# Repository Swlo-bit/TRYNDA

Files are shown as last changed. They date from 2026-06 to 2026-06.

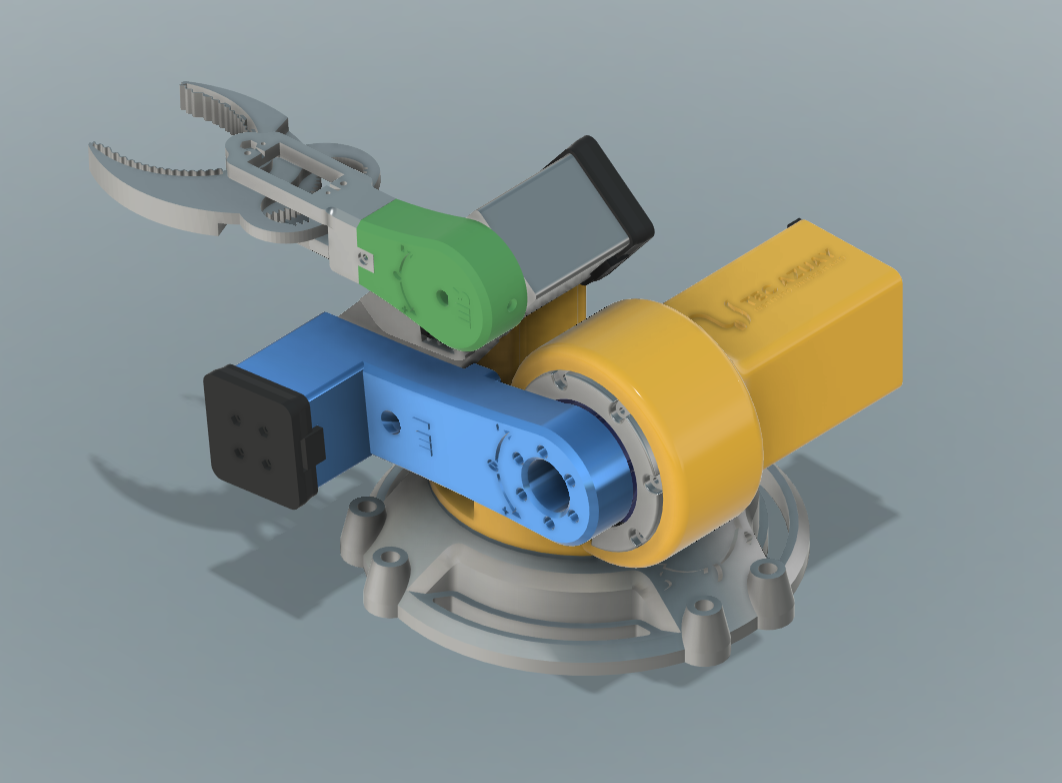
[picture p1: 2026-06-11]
TRYNDA 3D/Ensamble 1 TRYNDA.png

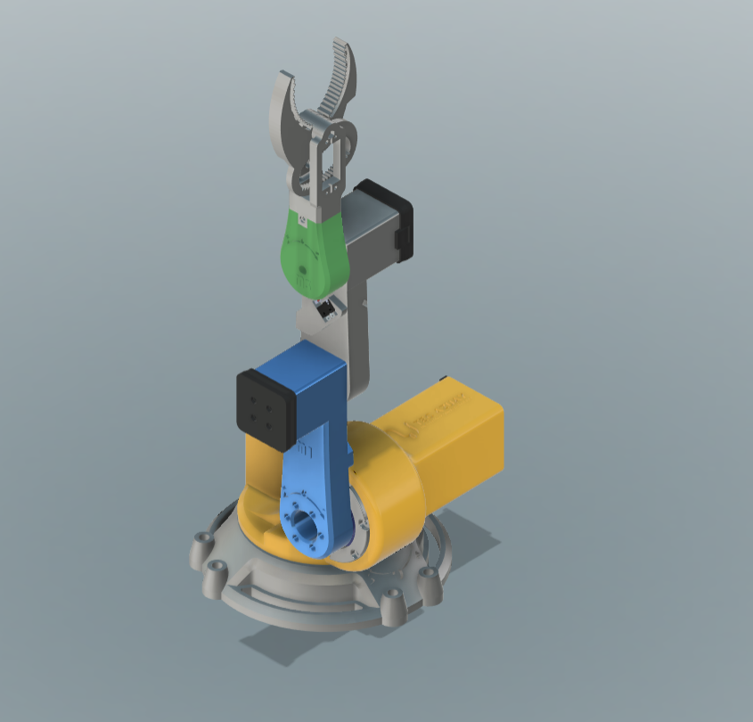
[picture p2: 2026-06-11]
TRYNDA 3D/Ensamble 2 TRYNDA.png

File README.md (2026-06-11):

# Robot Manipulador Mecatrónico de 4 GDL con Programación de Trayectorias

Ensamble 1 TRYNDA

## Descripción

Este proyecto corresponde al desarrollo de un robot manipulador de 4 grados de libertad más un gripper, realizado como proyecto integrador de la carrera de Mecatrónica.

El sistema reúne conocimientos adquiridos durante la formación académica en áreas como electrónica, automatización, control, programación, comunicaciones industriales, diseño mecánico, manufactura e impresión 3D.

El robot permite el control manual de cada articulación, la programación de posiciones mediante enseñanza por puntos, el posicionamiento por ángulos y la reproducción automática de trayectorias previamente almacenadas.

Aunque el sistema es completamente funcional, constituye una plataforma abierta que puede ser mejorada en futuras versiones mediante algoritmos avanzados de cinemática, planificación de trayectorias, visión artificial y sistemas de control más sofisticados.

## Características Principales

* Control de 4 grados de libertad más gripper.
* Homing automático mediante finales de carrera.
* Retroalimentación absoluta mediante encoders AS5600.
* Programación por puntos (Teach & Repeat).
* Programación por ángulos.
* Control manual mediante joystick.
* Comunicación inalámbrica ESP-NOW.
* Comunicación I²C entre controladores.
* Paro de emergencia local y remoto.
* Protección del gripper mediante monitoreo de corriente.
* Estructura fabricada principalmente mediante impresión 3D.

## Arquitectura de Comunicación y Sensado

Uno de los principales desafíos del proyecto fue la utilización de cuatro encoders magnéticos AS5600 para obtener la posición absoluta de cada articulación.

El AS5600 utiliza comunicación I²C y posee una dirección fija de fábrica (0x36), por lo que múltiples sensores no pueden coexistir en el mismo bus I²C sin generar conflictos de direccionamiento.

Para solucionar esta limitación se implementó una arquitectura distribuida:

* Cada articulación cuenta con un controlador dedicado.
* Cada Arduino Nano posee dos buses I²C independientes:

  * I²C hardware nativo para la comunicación con el sistema principal.
  * I²C por software (SoftwareWire) dedicado exclusivamente a su encoder AS5600.

De esta manera cada controlador puede comunicarse con su propio encoder utilizando una línea I²C aislada, evitando conflictos por direcciones duplicadas.

### Distribución de Comunicaciones

**ESP32 Maestro**

* Interfaz de usuario.
* Comunicación inalámbrica mediante ESP-NOW.

**ESP32 Esclavo**

* Coordinador general del robot.
* Comunicación ESP-NOW con el maestro.
* Comunicación I²C con los Arduino Nano.

**Arduino Nano Hombro**

* I²C hardware: comunicación con ESP32.
* I²C software: encoder AS5600.

**Arduino Nano Codo**

* I²C hardware: comunicación con ESP32.
* I²C software: encoder AS5600.

**Arduino Nano Muñeca**

* I²C hardware: comunicación con ESP32.
* I²C software: encoder AS5600.

Gracias a esta arquitectura fue posible utilizar múltiples encoders AS5600 simultáneamente sin necesidad de multiplexores I²C adicionales.
Esta solución permitió evitar el uso de multiplexores I²C externos, simplificando el hardware y distribuyendo la carga de procesamiento entre varios microcontroladores.

## Arquitectura del Sistema

El sistema está dividido en varios controladores distribuidos:

### ESP32 Maestro

Responsable de:

* Interfaz de usuario.
* Pantalla OLED.
* Teclado matricial.
* Joystick.
* Selección de modos de operación.
* Envío de comandos mediante ESP-NOW.

### ESP32 Esclavo M0

Responsable de:

* Coordinación general del robot.
* Control del eje Base (M1).
* Control del gripper.
* Gestión de trayectorias.
* Supervisión de seguridad.
* Comunicación con los Arduino Nano.

### Arduino Nano M1 (Hombro)

Responsable del control cerrado del eje hombro utilizando:

* Motor paso a paso.
* Encoder AS5600.
* Final de carrera para homing.

### Arduino Nano M2 (Codo)

Responsable del control cerrado del eje codo utilizando:

* Motor paso a paso.
* Encoder AS5600.
* Final de carrera para homing.

### Arduino Nano M3 (Muñeca)

Responsable del control cerrado del eje muñeca utilizando:

* Motor paso a paso.
* Encoder AS5600.
* Final de carrera para homing.

## Modos de Operación

El robot incorpora tres modos principales de programación y control, permitiendo tanto la manipulación manual como la ejecución automática de trayectorias.

### 1. Programación por Ángulos Incrementales

En este modo el operador selecciona una articulación específica y posteriormente introduce un valor angular mediante el teclado matricial.

El valor ingresado no corresponde a una posición absoluta, sino a un incremento respecto a la posición actual de la articulación.

Por ejemplo:

* Posición actual: 45°
* Valor ingresado: +20°
* Nueva posición objetivo: 65°

O bien:

* Posición actual: 45°
* Valor ingresado: -10°
* Nueva posición objetivo: 35°

Cada controlador calcula internamente la nueva posición objetivo sumando o restando el incremento al ángulo absoluto medido por su encoder AS5600.

### 2. Control Manual por Joystick

Este modo permite mover individualmente cualquiera de las articulaciones utilizando el joystick integrado en el control maestro.

El operador selecciona el eje deseado y puede realizar movimientos manuales en ambos sentidos para posicionar el robot de forma rápida e intuitiva.

Este modo es utilizado principalmente para:

* Posicionar manualmente el manipulador.
* Realizar pruebas de funcionamiento.
* Enseñar trayectorias.
* Ajustar posiciones antes de almacenarlas.

### 3. Programación por Puntos

Este modo permite crear trayectorias mediante enseñanza directa.

El usuario puede:

* Liberar una articulación específica.
* Liberar todas las articulaciones simultáneamente.
* Posicionar el robot manualmente.
* Posicionar el robot mediante joystick.
* Fijar nuevamente las articulaciones.
* Almacenar la posición actual como un punto de trayectoria.

Cada vez que se guarda un punto, el sistema registra simultáneamente:

* Posición de la base.
* Posición del hombro.
* Posición del codo.
* Posición de la muñeca.
* Posición del gripper.

Es decir, cada punto representa el estado completo del robot en un instante determinado.

Los puntos almacenados pueden reproducirse posteriormente de manera automática, permitiendo ejecutar secuencias repetitivas sin necesidad de reprogramación.

Actualmente el sistema permite almacenar hasta 20 puntos por rutina, valor que puede ampliarse en futuras versiones.

## Sistema de Seguridad

El robot incorpora múltiples mecanismos de seguridad:

* Paro de emergencia físico.
* Paro de emergencia remoto.
* Límites mecánicos por software.
* Homing obligatorio antes de operación.
* Supervisión de corriente en el gripper mediante INA219.
* Detección de fallos de comunicación con encoders AS5600.

## Hardware Utilizado

### Controladores

* 2 ESP32
* 3 Arduino Nano

### Sensores

* 4 Encoders magnéticos AS5600
* 1 Sensor de corriente INA219
* Finales de carrera mecánicos

### Actuadores

* 1  NEMA 23 (M1)
* 1  NEMA 17 (M0)
* 2  NEMA 17 5:1 (M2 & M3)
* 1  MG996R (Gripper o M5)

### Electrónica de Potencia

* 3 Driver TB6600
* Driver DM556
* Fuente 12V 10A
* 2 Convertidores LM2596

### Mecánica

* Piezas impresas en 3D
* Rodamientos
* Insertos roscados
* Pernos y tuercas
* Acoples mecánicos

## Fabricación

La estructura mecánica fue diseñada principalmente para fabricación mediante impresión 3D.

Debido a las altas cargas transmitidas por una de las articulaciones, fue necesario fabricar una pieza mecánica metálica para la unión del motor correspondiente, ya que la versión impresa no soportaba los esfuerzos generados durante la operación.

## Posibles Mejoras Futuras
* Implementación de cinemática inversa.
* Planificación automática de trayectorias.
* Interpolación lineal y circular.
* Integración con ROS.
* Sistema de visión artificial.
* Detección y seguimiento de objetos.
* Interfaz gráfica para programación.
* Monitoreo remoto mediante WiFi.
* Control avanzado de movimiento.

## Autores

* Sebastian A. Saico
* Saul Andrés Sánchez Barbecho
  * Email: saulsanchezbarbecho@gmail.com
* Jonnathan A. Valdez
* Edwin J. Suqui

Tecnología Superior en Mecatrónica
TECAZUAY – Ecuador

TRYNDA real

TRYNDA real 2

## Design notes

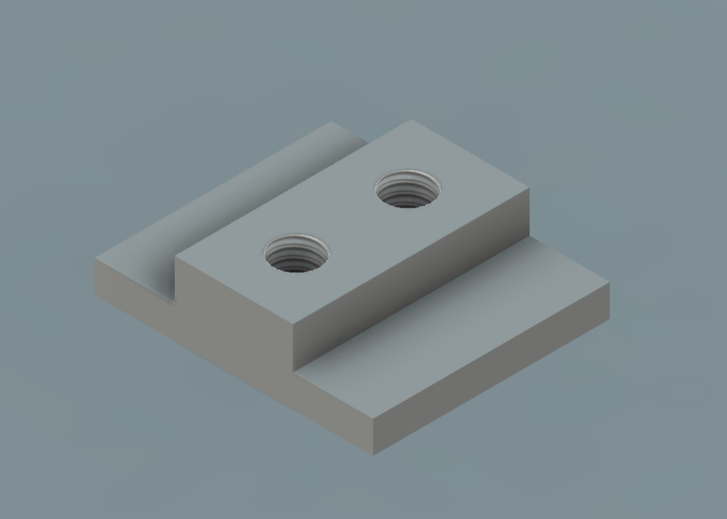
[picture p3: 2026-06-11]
Piezas Mecanicas/Soporte Nema M2.png

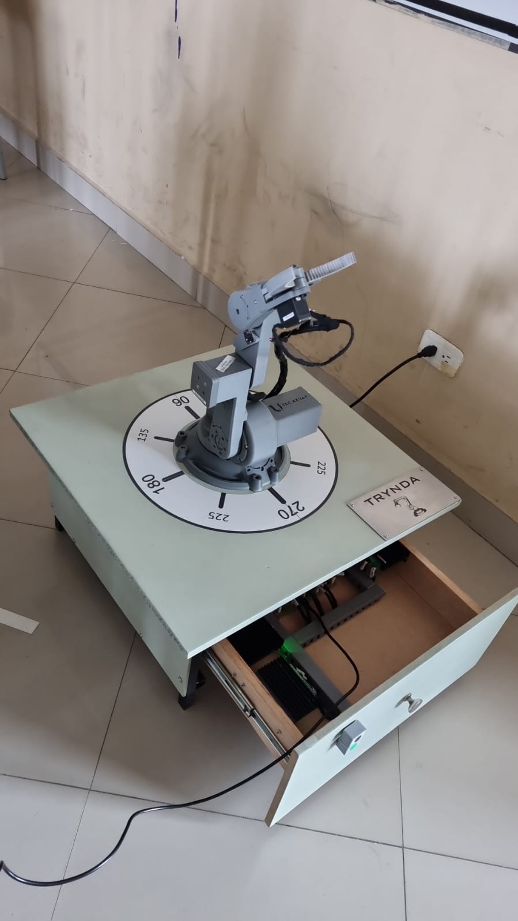
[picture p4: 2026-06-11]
TRYNDA 3D/TRYNDA real 2.jpeg

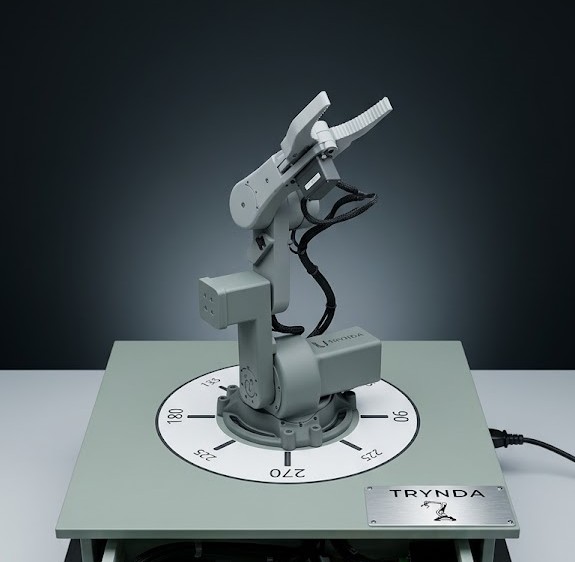
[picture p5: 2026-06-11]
TRYNDA 3D/TRYNDA real.jpeg

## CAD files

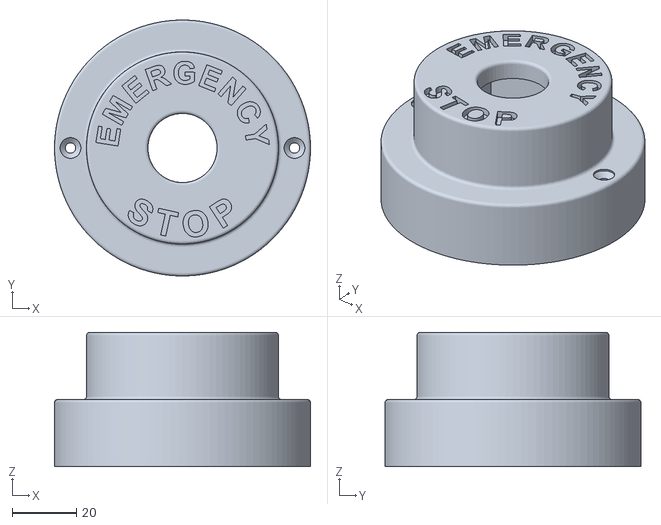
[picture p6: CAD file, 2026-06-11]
TRYNDA 3D/Emergency Stop.stl
80.0 x 80.0 x 42.0

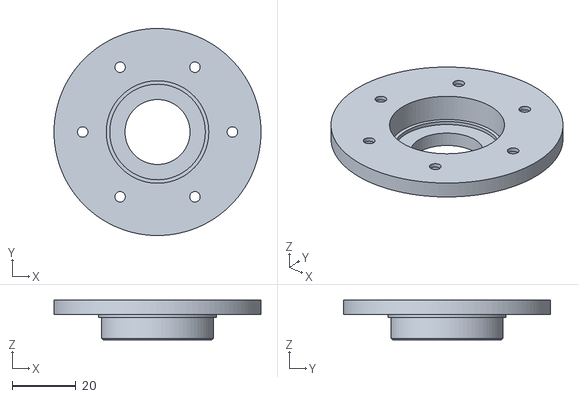
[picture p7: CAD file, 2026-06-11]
TRYNDA 3D/reductor/Soporte entrada.stl
65.0 x 65.0 x 12.5

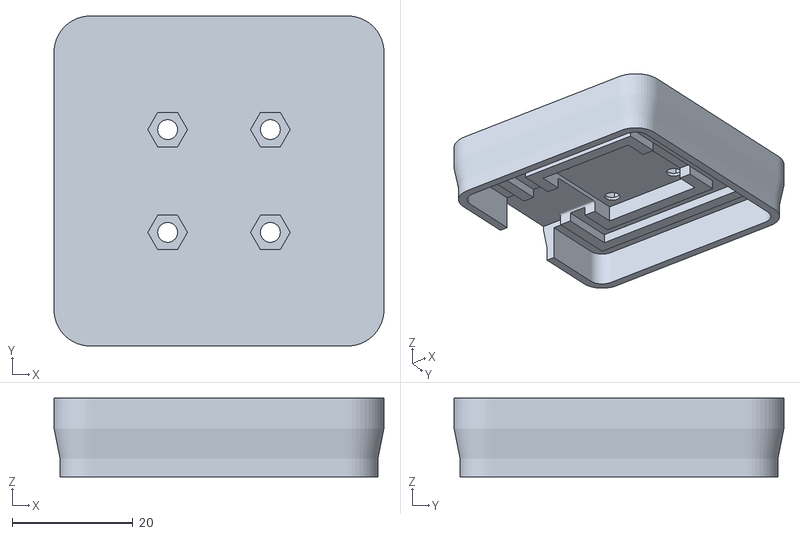
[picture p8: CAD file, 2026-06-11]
TRYNDA 3D/Bracket M2 TRYNDA.stl
54.6 x 54.6 x 13.0

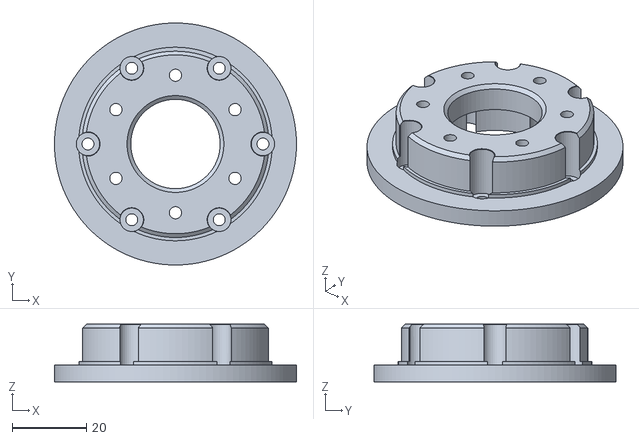
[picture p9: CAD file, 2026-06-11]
TRYNDA 3D/reductor/Salida reducida TRYNDA.stl
65.0 x 65.0 x 15.5

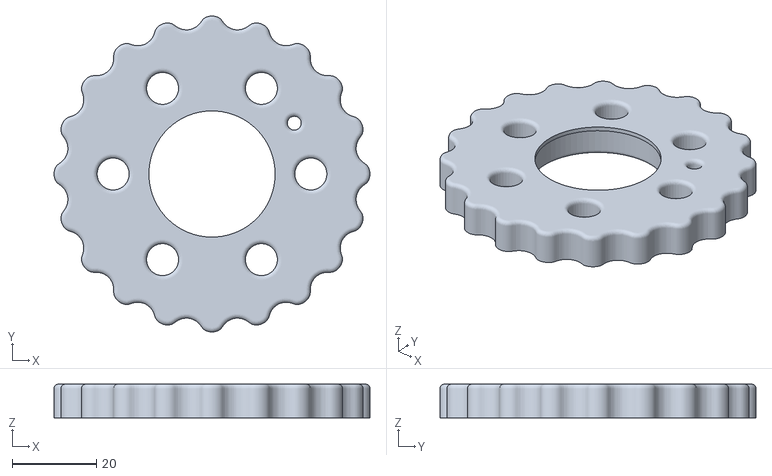
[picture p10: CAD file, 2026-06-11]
TRYNDA 3D/reductor/cycloid1.stl
75.1 x 75.1 x 8.00

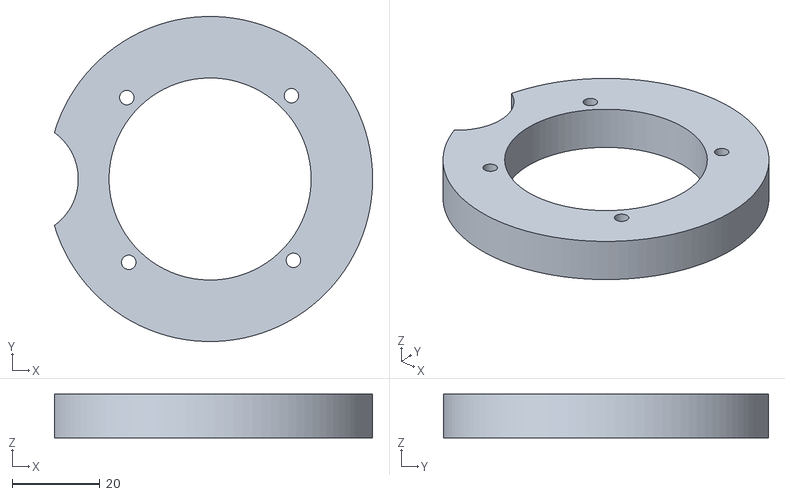
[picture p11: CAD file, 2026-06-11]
TRYNDA 3D/Tapa acople Base TRYNDA.stl
72.5 x 74.0 x 10.0

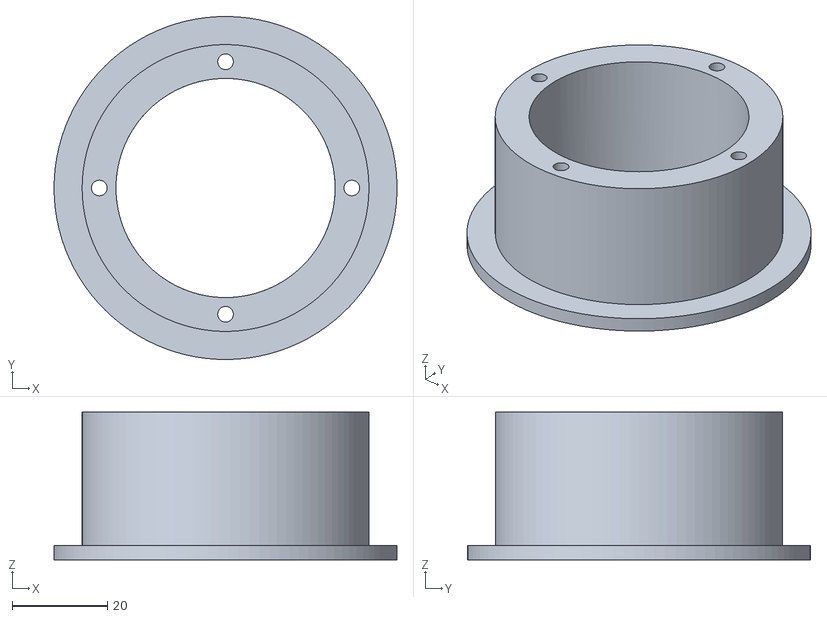
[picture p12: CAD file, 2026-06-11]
TRYNDA 3D/acople base TRYNDA.stl
72.0 x 72.0 x 31.0

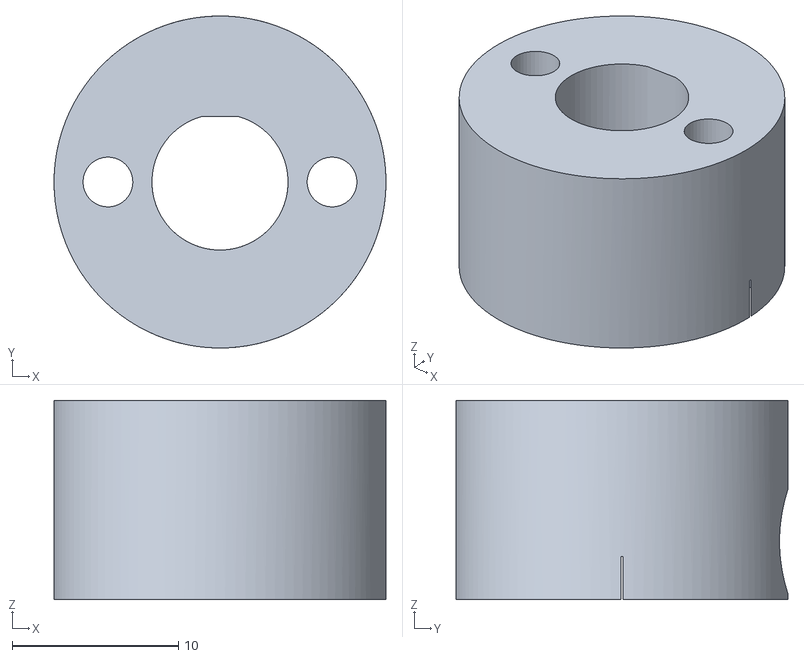
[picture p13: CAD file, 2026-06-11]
TRYNDA 3D/reductor/CAM input_.stl
20.0 x 20.0 x 12.0

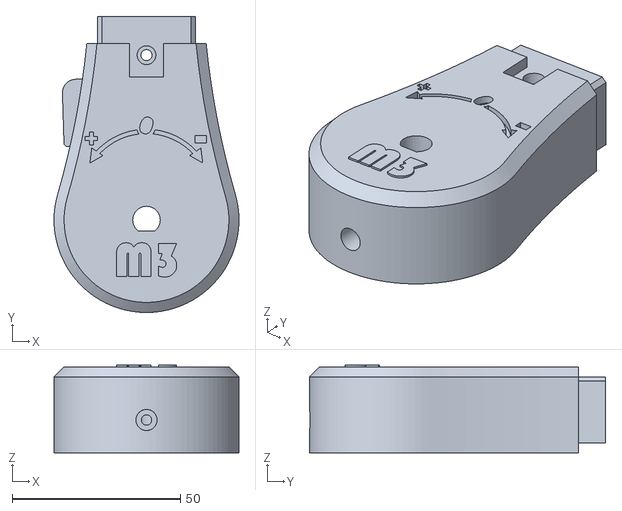
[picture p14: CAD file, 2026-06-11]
TRYNDA 3D/Articulacion M3 TRYNDA.stl
55.0 x 88.0 x 26.1

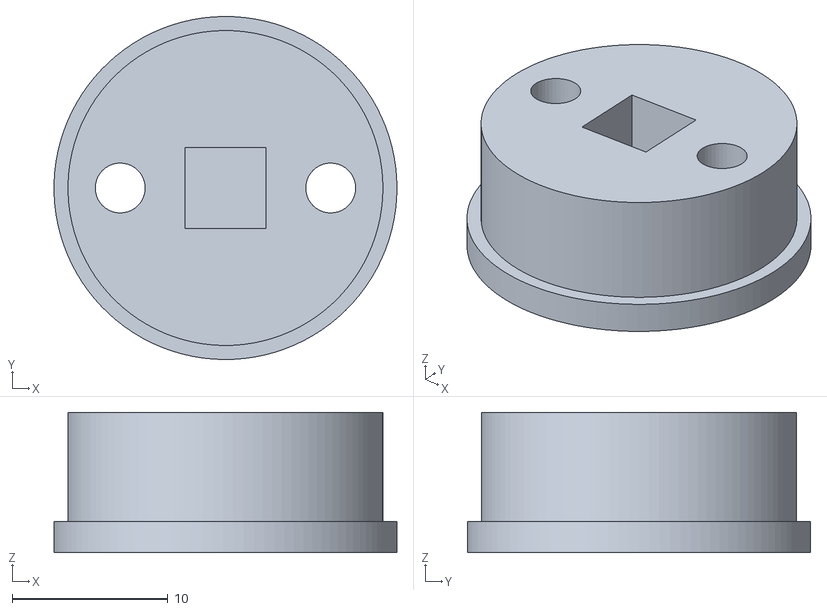
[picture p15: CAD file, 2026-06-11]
TRYNDA 3D/reductor/cam4.stl
22.0 x 22.0 x 9.00

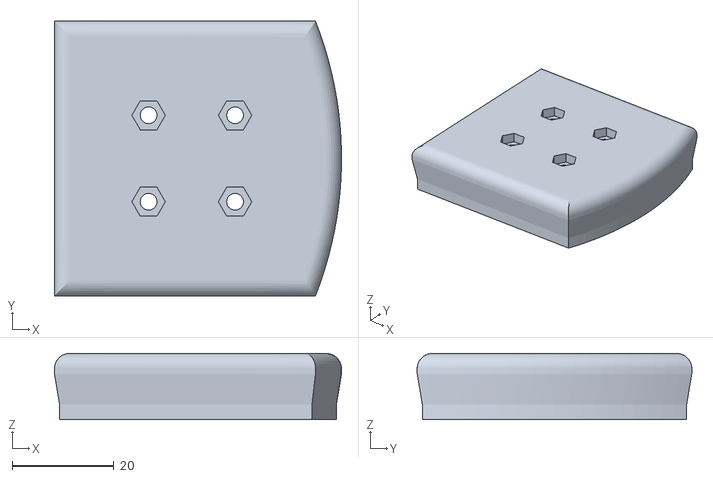
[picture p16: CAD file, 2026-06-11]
TRYNDA 3D/Bracket M0 TRYNDA.stl
56.4 x 54.0 x 13.0

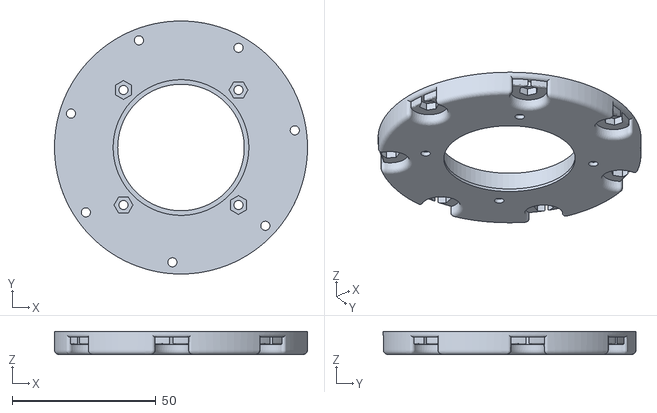
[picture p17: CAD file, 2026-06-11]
TRYNDA 3D/reductor/Cuerpo Bajo.stl
88.0 x 88.0 x 8.00

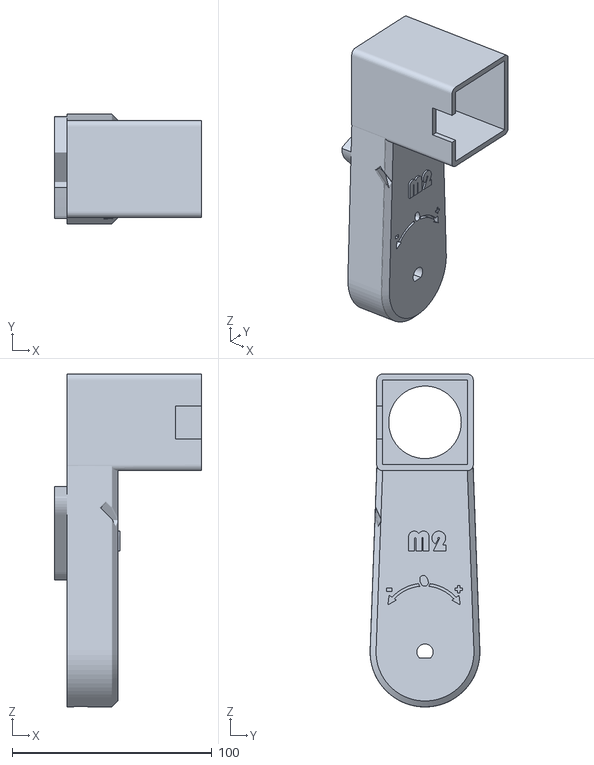
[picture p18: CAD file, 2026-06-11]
TRYNDA 3D/Articulacion M2 TRYNDA.stl
73.8 x 55.0 x 166.7

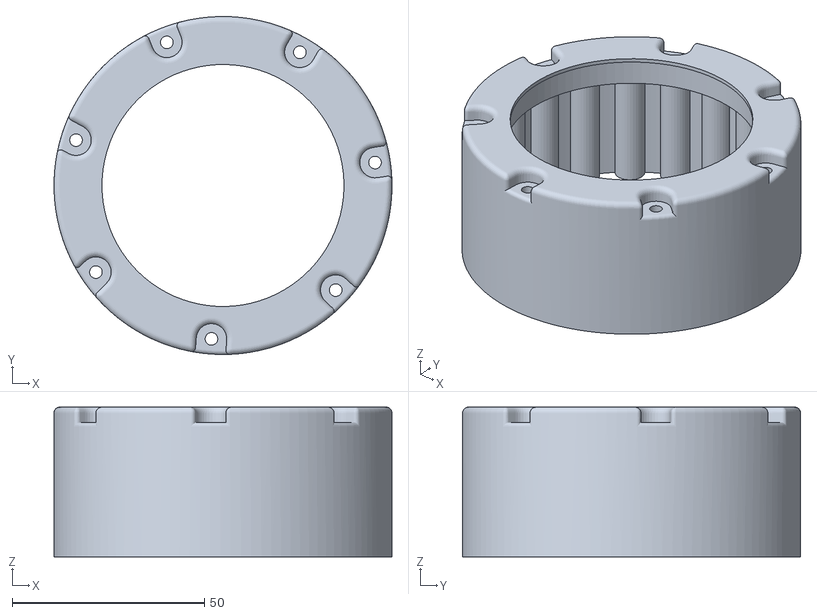
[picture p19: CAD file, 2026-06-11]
TRYNDA 3D/reductor/Soporte Exterior TRYNDA.stl
88.0 x 88.0 x 39.0

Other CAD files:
TRYNDA 3D/reductor/CAM 1 - 2.stl
TRYNDA 3D/Base TRYNDA.stl
TRYNDA 3D/reductor/cycloid2.stl
TRYNDA 3D/Articulacion M1 TRYNDA.stl
TRYNDA 3D/Bracket M1 TRYNDA.stl
TRYNDA 3D/reductor/Acople nema23.stl
TRYNDA 3D/reductor/CAM 3.stl

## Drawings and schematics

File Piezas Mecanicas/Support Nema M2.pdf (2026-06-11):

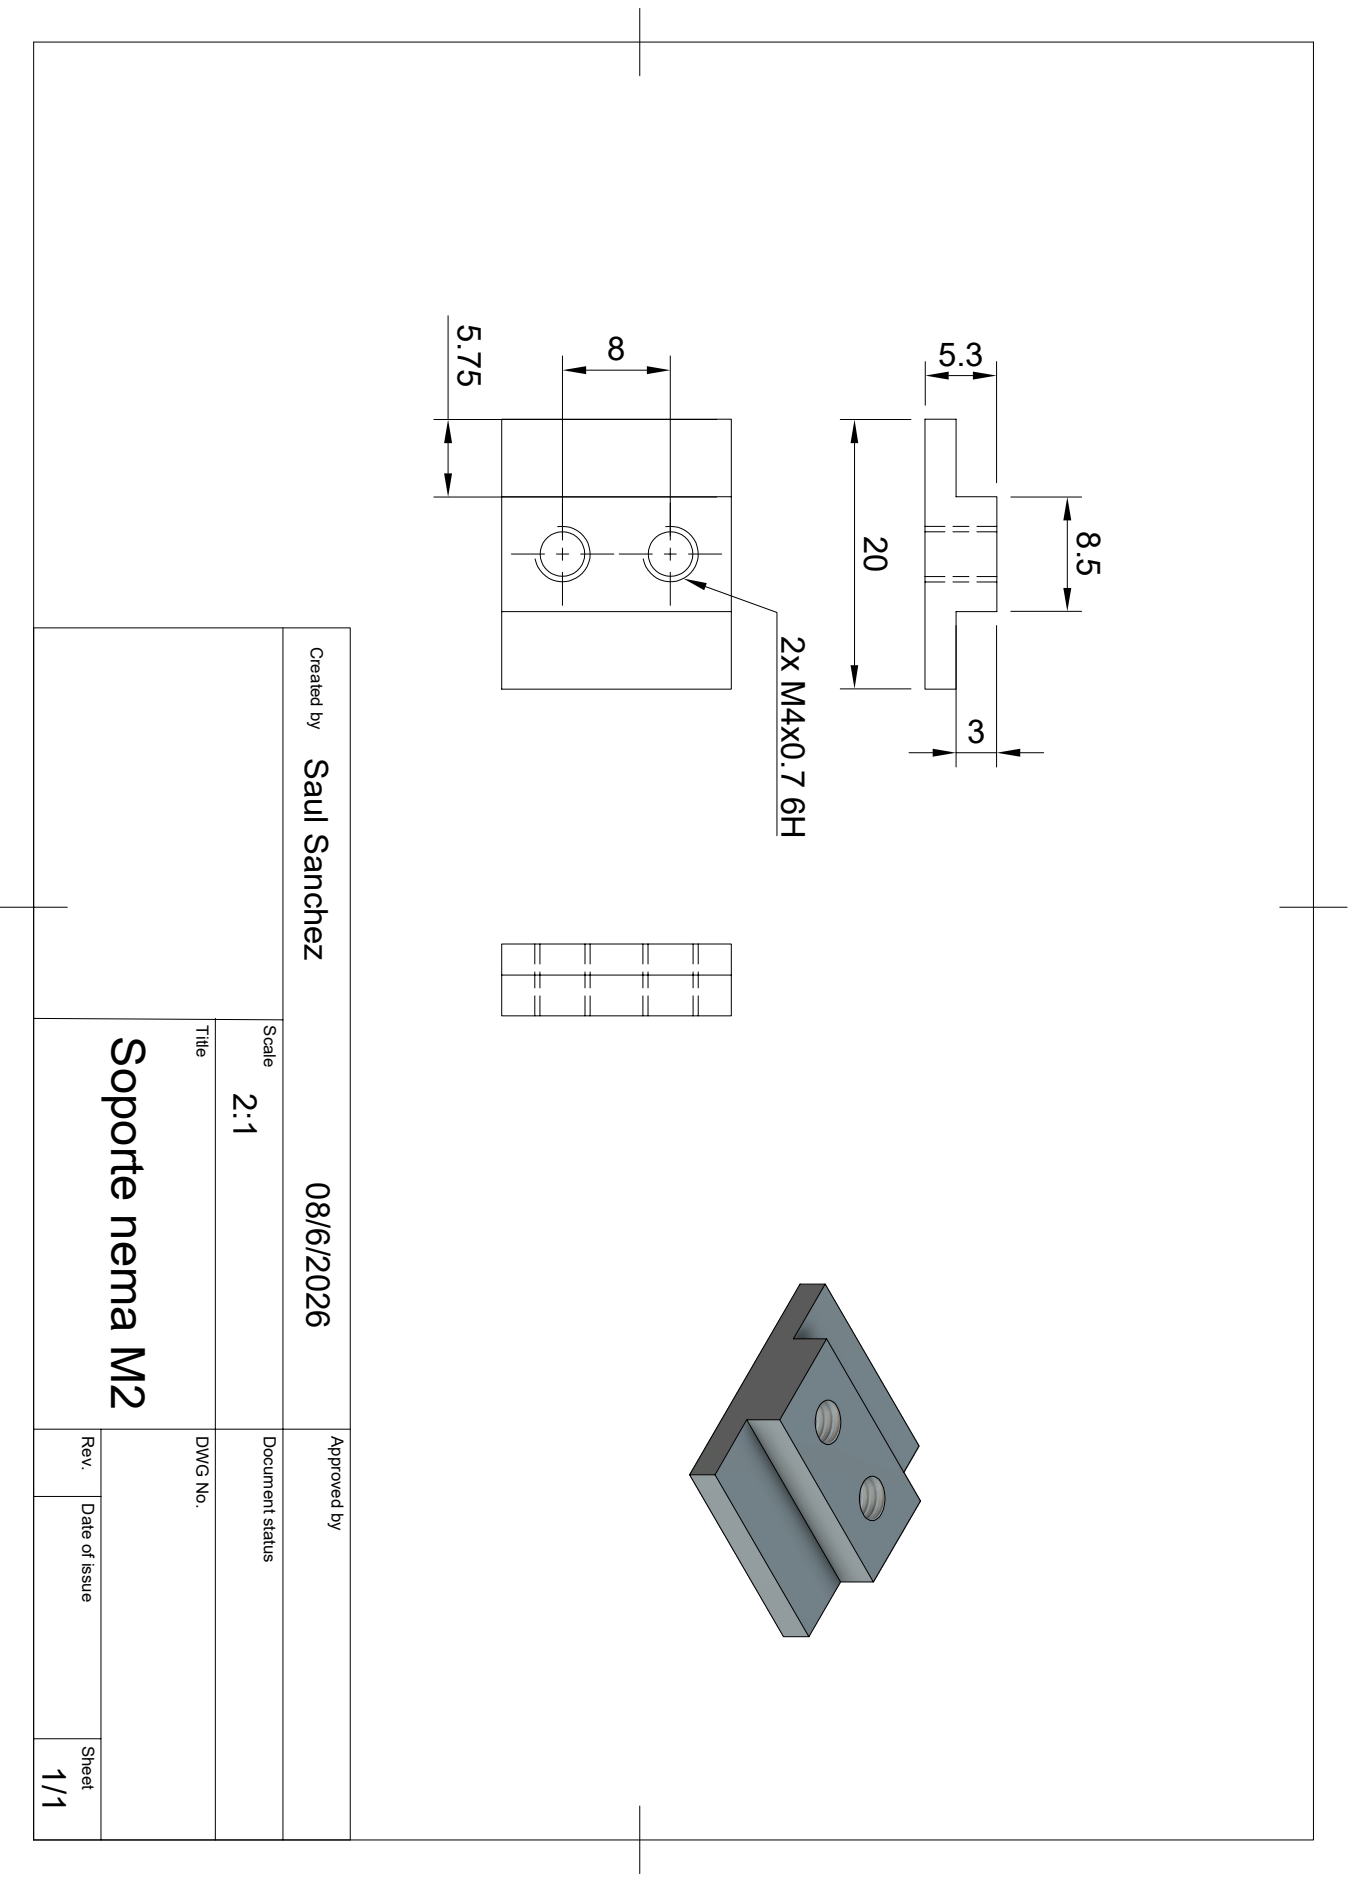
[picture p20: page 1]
8 Created by Approved by Title DWG No.; Scale Document status Rev. Date of issue Sheet; Soporte nema M2; Saul Sanchez

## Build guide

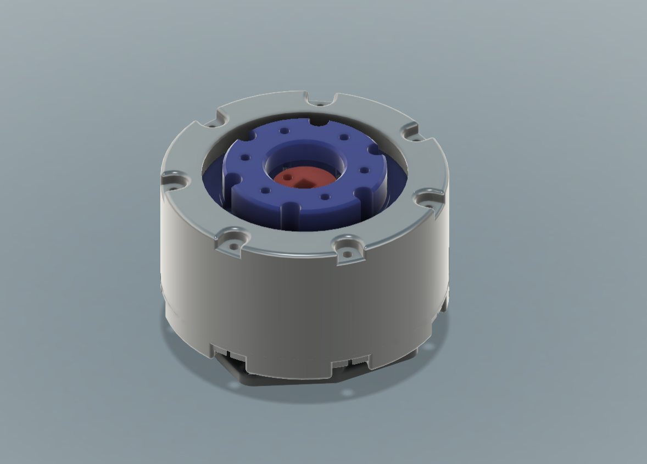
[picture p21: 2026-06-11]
TRYNDA 3D/reductor/Ensamble Reducotr Nema 23.png

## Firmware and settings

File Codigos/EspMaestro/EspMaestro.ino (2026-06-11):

#include <WiFi.h>
#include <esp_now.h>
#include <U8g2lib.h>
#include <Wire.h>
#include <Keypad.h>

U8G2_SH1106_128X64_NONAME_F_HW_I2C oled(U8G2_R0, U8X8_PIN_NONE);

#define PIN_PARO 23 
bool sistemaBloqueado = false;
bool paroRemoto = false;

#define VRX 34 
#define VRY 35 
#define SW_PIN 5 
int centroVRX = 0, centroVRY = 0; 

#define LED_JOYSTICK 15 
#define LED_ANGULOS   2 
#define LED_PUNTOS    4 

const byte FILAS = 4;
const byte COLS  = 4;
char teclas[FILAS][COLS] = {
  {'1','2','3','A'},
  {'4','5','6','B'},
  {'7','8','9','C'},
  {'*','0','#','D'}
};

byte pinesFilas[FILAS]    = {27, 14, 12, 13};
byte pinesColumnas[COLS]  = {32, 33, 25, 26};
Keypad keypad = Keypad(makeKeymap(teclas), pinesFilas, pinesColumnas, FILAS, COLS);

uint8_t slaveMAC[] = {0x88, 0x57, 0x21, 0x8B, 0x3D, 0x58};
typedef struct { char msg[24]; } Packet;
Packet packet;

bool enControlJoystick = false;     
bool enSeleccionMotor = false;    
bool enDigitacionAngulo = false; 
int menuActual = 0;
int cursorMenu = 0;
int motorSeleccionado = 1;

const int NUM_MOTORES = 5;
String nombresMotores[NUM_MOTORES] = {"Base", "Hombro", "Codo", "Muneca", "Garra"};
int cursorMotor = 0;
String estadoMotor = "STOP";
String ultimoEstado = "";
int puntosGuardadosCount = 0;
String inputAngulo = ""; 

unsigned long lastButtonPress = 0;
const int doubleClickTime = 500;
bool lastButtonState = HIGH;

void onDataRecv(const esp_now_recv_info_t *info, const uint8_t *data, int len) {
  memcpy(&packet, data, sizeof(packet));
  String msg = String(packet.msg); msg.trim();
  if (msg == "EMERGENCIA_ON") paroRemoto = true;
  else if (msg == "EMERGENCIA_OFF") paroRemoto = false;
}

// 🔥 NUEVA FUNCIÓN: Saludo de inicio
void saludoInicial() {
  oled.setFont(u8g2_font_ncenB14_tr);
  
  oled.clearBuffer();
  int w1 = oled.getStrWidth("Hello!");
  oled.drawStr((128 - w1) / 2, 40, "Hello!");
  oled.sendBuffer();
  delay(1200);

  oled.clearBuffer();
  int w2 = oled.getStrWidth("Hola!");
  oled.drawStr((128 - w2) / 2, 40, "Hola!");
  oled.sendBuffer();
  delay(1200);

  oled.clearBuffer();
  int w3 = oled.getStrWidth("Ni hao!");
  oled.drawStr((128 - w3) / 2, 40, "Ni hao!");
  oled.sendBuffer();
  delay(1200);
}

void pantallaBloqueo() {
  static bool parpadeo = false;
  oled.clearBuffer();
  if (parpadeo) oled.drawFrame(0, 0, 128, 64);
  oled.drawFrame(2, 2, 124, 60);
  oled.setFont(u8g2_font_ncenB10_tr);
  oled.drawStr(30, 28, "BLOQUEO");
  oled.setFont(u8g2_font_6x10_tr);
  if (paroRemoto) oled.drawStr(20, 48, "PARO ESCLAVO");
  else oled.drawStr(20, 48, "PARO MAESTRO");
  oled.sendBuffer();
  parpadeo = !parpadeo;
}

void pantallaLiberacion() {
  oled.clearBuffer(); oled.drawBox(4, 12, 120, 40); oled.setDrawColor(0);
  oled.setFont(u8g2_font_ncenB08_tr); oled.drawStr(20, 30, "SISTEMA LIBRE");
  oled.setFont(u8g2_font_5x8_tf); oled.drawStr(15, 45, "LISTO PARA OPERAR");
  oled.setDrawColor(1); oled.sendBuffer(); delay(1500);
}

void apagarLeds() {
  digitalWrite(LED_JOYSTICK, LOW); digitalWrite(LED_ANGULOS, LOW); digitalWrite(LED_PUNTOS, LOW);
}

void enviarESPNow(String txt) {
  txt.toCharArray(packet.msg, sizeof(packet.msg));
  esp_now_send(slaveMAC, (uint8_t*)&packet, sizeof(packet));
}

void drawIcon(uint8_t type, int x, int y) {
  switch (type) {
    case 0: oled.drawCircle(x+4,y,2); oled.drawLine(x+4,y-4,x+4,y+4); oled.drawLine(x,y,x+8,y); break;
    case 1: oled.drawCircle(x+4,y,1); oled.drawArc(x+4,y,6,0,90); break;
    case 2: oled.drawCircle(x+4,y+2,3); oled.drawLine(x+4,y-4,x+4,y+2); break;
  }
}

void drawItem(uint8_t pos, uint8_t index, const char* text) {
  int y = 4 + pos * 20;
  if (cursorMenu == index) oled.drawFrame(0, y, 128, 18);
  drawIcon(index, 6, y + 9); oled.drawStr(24, y + 13, text);
}

void mostrarMenuPrincipal() {
  apagarLeds(); oled.clearBuffer(); oled.setFont(u8g2_font_5x8_tf);
  drawItem(0, 0, "Prog. Puntos"); drawItem(1, 1, "Prog. Angulos"); drawItem(2, 2, "Prog. Joystick");
  oled.sendBuffer();
}

void mostrarMenuMotores() {
  oled.clearBuffer(); oled.setFont(u8g2_font_5x8_tf);
  if(menuActual == 1) oled.drawStr(0, 8, "MODO PUNTOS");
  else if(menuActual == 2) oled.drawStr(0, 8, "MODO ANGULOS");
  else oled.drawStr(0, 8, "MODO JOYSTICK");
  
  for (int i = 0; i < NUM_MOTORES; i++) {
    int y = 20 + i * 10;
    if (i == cursorMotor) oled.drawStr(0, y, ">"); 
    oled.drawStr(10, y, ("M" + String(i+1) + ": " + nombresMotores[i]).c_str());
  }
  oled.sendBuffer();
}

void mostrarIngresoAngulo() {
  oled.clearBuffer(); oled.setFont(u8g2_font_6x10_tf);
  oled.drawStr(0, 12, ("ANG: " + nombresMotores[motorSeleccionado-1]).c_str());
  oled.setFont(u8g2_font_ncenB14_tr); oled.drawStr(10, 40, inputAngulo.c_str());
  oled.setFont(u8g2_font_5x8_tf); oled.drawStr(0, 63, "*: +/-  D:Back  #:Go");
  oled.sendBuffer();
}

void mostrarEstadoMotor(String motor, String estado) {
  oled.clearBuffer(); oled.setFont(u8g2_font_5x8_tf);
  oled.drawStr(0, 10, ("MOTOR: " + motor).c_str());
  
  if (menuActual == 3) { 
    int cx = 64; int cy = 40;
    if (estado == "NEGATIVE") oled.drawBox(cx-12, cy-4, 24, 6);
    else if (estado == "POSITIVE") { oled.drawBox(cx-12, cy-4, 24, 6); oled.drawBox(cx-3, cy-13, 6, 24); } 
    else oled.drawDisc(cx, cy, 6); 
    oled.drawStr(0, 62, estado.c_str());
  } 
  else if (menuActual == 1) { 
    // 🔥 AUTO-CENTRADO para que encaje perfecto "POSITIVE" o "FREE"
    oled.setFont(u8g2_font_ncenB10_tr);
    int textWidth = oled.getStrWidth(estado.c_str());
    oled.drawStr((128 - textWidth) / 2, 35, estado.c_str()); 
    
    oled.setFont(u8g2_font_5x8_tf);
    oled.drawStr(0, 53, "*:Lib #:Fij   Pts:");
    oled.setCursor(95, 53); oled.print(puntosGuardadosCount);
    oled.drawStr(0, 63, "1:LibTodos 2:FijTodos");
  }
  
  oled.sendBuffer();
}

void mostrarTexto(String l1, String l2 = "") {
  oled.clearBuffer(); oled.setFont(u8g2_font_5x8_tf);
  oled.drawStr(0, 22, l1.c_str()); oled.drawStr(0, 40, l2.c_str());
  oled.sendBuffer();
}

void controlJoystickLoop() {
  int x = analogRead(VRX), y = analogRead(VRY);
  const int DZ = 700; 
  int diffX = abs(x - centroVRX), diffY = abs(y - centroVRY);
  if (diffX > diffY && diffX > DZ) estadoMotor = (x < centroVRX) ? "NEGATIVE" : "POSITIVE"; 
  else if (diffY > diffX && diffY > DZ) estadoMotor = (y < centroVRY) ? "NEGATIVE" : "POSITIVE"; 
  else estadoMotor = "STOP";

  if (estadoMotor != ultimoEstado) {
    ultimoEstado = estadoMotor;
    enviarESPNow("M" + String(motorSeleccionado) + "_" + estadoMotor);
    mostrarEstadoMotor(nombresMotores[motorSeleccionado-1], estadoMotor);
  }
}

void setup() {
  pinMode(PIN_PARO, INPUT_PULLUP);
  pinMode(LED_JOYSTICK, OUTPUT); pinMode(LED_ANGULOS, OUTPUT); pinMode(LED_PUNTOS, OUTPUT);
  pinMode(SW_PIN, INPUT_PULLUP);
  apagarLeds();
  
  Wire.begin(21, 22); 
  oled.begin();

  saludoInicial();

  WiFi.mode(WIFI_STA); esp_now_init(); esp_now_register_recv_cb(onDataRecv);
  esp_now_peer_info_t peerInfo = {}; memcpy(peerInfo.peer_addr, slaveMAC, 6); esp_now_add_peer(&peerInfo);
  long sumX = 0, sumY = 0;
  for (int i = 0; i < 20; i++) { sumX += analogRead(VRX); sumY += analogRead(VRY); delay(10); }
  centroVRX = sumX / 20; centroVRY = sumY / 20;
  
  mostrarMenuPrincipal();
}

void loop() {
  if (digitalRead(PIN_PARO) == HIGH || paroRemoto == true) { 
    if (!sistemaBloqueado) { 
      enviarESPNow("EMERGENCIA_ON"); 
      enviarESPNow("STOP");          
      sistemaBloqueado = true; 
    }
    pantallaBloqueo(); delay(200); return;
  } 
  if (sistemaBloqueado && digitalRead(PIN_PARO) == LOW && paroRemoto == false) {
    enviarESPNow("EMERGENCIA_OFF");  
    pantallaLiberacion(); sistemaBloqueado = false; mostrarMenuPrincipal(); return;
  }

  bool btn = digitalRead(SW_PIN);
  if (btn == LOW && lastButtonState == HIGH) {
    unsigned long now = millis();
    if (now - lastButtonPress < doubleClickTime) {
      enviarESPNow("M1_HOME");
      mostrarTexto("CALIBRANDO...", "Base y Nanos");
      delay(1200);
      if (enControlJoystick) mostrarEstadoMotor(nombresMotores[motorSeleccionado-1], "STOP");
      else if (enDigitacionAngulo) mostrarIngresoAngulo();
      else mostrarMenuPrincipal();
    }
    lastButtonPress = now;
  }
  lastButtonState = btn;

  char t = keypad.getKey();

  if (!t) { 
    if (enControlJoystick && (menuActual == 3 || menuActual == 1)) controlJoystickLoop(); 
    return; 
  }

  if (menuActual == 0) {
    if (t == '*') { cursorMenu = (cursorMenu + 1) % 3; mostrarMenuPrincipal(); }
    if (t == '#') { 
      menuActual = cursorMenu + 1; enSeleccionMotor = true; apagarLeds();
      if(menuActual == 1) digitalWrite(LED_PUNTOS, HIGH);
      if(menuActual == 2) digitalWrite(LED_ANGULOS, HIGH);
      if(menuActual == 3) digitalWrite(LED_JOYSTICK, HIGH);
      mostrarMenuMotores();
    }
  } 
  else {
    if (enSeleccionMotor) {
      if (t == '*') { cursorMotor = (cursorMotor + 1) % NUM_MOTORES; mostrarMenuMotores(); }
      if (t == 'D') { menuActual = 0; mostrarMenuPrincipal(); }
      if (t == '#') { 
        motorSeleccionado = cursorMotor + 1; enSeleccionMotor = false;
        if(menuActual == 2) { enDigitacionAngulo = true; inputAngulo = ""; mostrarIngresoAngulo(); }
        else { enControlJoystick = true; ultimoEstado = ""; mostrarEstadoMotor(nombresMotores[motorSeleccionado-1], "STOP"); }
      }
    } 
    else if (enControlJoystick) {
      if (menuActual == 1) { 
        if (t == '*') { enviarESPNow("M" + String(motorSeleccionado) + "_FREE"); mostrarTexto("LIBERADO (Mano)", "M" + String(motorSeleccionado)); delay(600); mostrarEstadoMotor(nombresMotores[motorSeleccionado-1], "FREE"); }
        if (t == '#') { enviarESPNow("M" + String(motorSeleccionado) + "_LOCK"); mostrarTexto("BLOQUEADO", "Posicion Fija"); delay(600); mostrarEstadoMotor(nombresMotores[motorSeleccionado-1], "STOP"); }
        
        if (t == '1') { enviarESPNow("FREE_ALL"); mostrarTexto("LIBERANDO...", "Todos los ejes"); delay(800); mostrarEstadoMotor(nombresMotores[motorSeleccionado-1], "FREE"); }
        if (t == '2') { enviarESPNow("LOCK_ALL"); mostrarTexto("BLOQUEANDO...", "Todos los ejes"); delay(800); mostrarEstadoMotor(nombresMotores[motorSeleccionado-1], "STOP"); }
        
        if (t == 'A') { enviarESPNow("SAVE"); if(puntosGuardadosCount < 20) puntosGuardadosCount++; mostrarTexto("Punto Guardado", "Ruta"); delay(600); mostrarEstadoMotor(nombresMotores[motorSeleccionado-1], "STOP"); }
        if (t == 'B') { enviarESPNow("DELETE"); if(puntosGuardadosCount > 0) puntosGuardadosCount--; mostrarTexto("Borrado", "Ultimo Punto"); delay(600); mostrarEstadoMotor(nombresMotores[motorSeleccionado-1], "STOP"); }
        if (t == 'C') { enviarESPNow("PLAY"); mostrarTexto("Reproduciendo...", "En Orden"); delay(1200); mostrarEstadoMotor(nombresMotores[motorSeleccionado-1], "STOP"); }
      }
      if (t == 'D') { enControlJoystick = false; enSeleccionMotor = true; enviarESPNow("STOP"); mostrarMenuMotores(); }
    }
    else if (enDigitacionAngulo) { 
      if (t >= '0' && t <= '9') { if (inputAngulo.length() < 7) inputAngulo += t; mostrarIngresoAngulo(); }
      if (t == '*') { if (inputAngulo.startsWith("-")) inputAngulo.remove(0, 1); else inputAngulo = "-" + inputAngulo; mostrarIngresoAngulo(); }
      if (t == 'D') { enDigitacionAngulo = false; enSeleccionMotor = true; mostrarMenuMotores(); }
      if (t == '#') {
        if (inputAngulo.length() > 0) {
          enviarESPNow("GOTO_M" + String(motorSeleccionado) + ":" + inputAngulo);
          mostrarTexto("ENVIADO!", inputAngulo + " Grados"); delay(800);
        }
        enDigitacionAngulo = false; enSeleccionMotor = true; mostrarMenuMotores();
      }
    }
  }
}

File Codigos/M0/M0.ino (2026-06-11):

#include <WiFi.h>
#include <esp_now.h>
#include <Wire.h>
#include <Adafruit_INA219.h> 
#include <ESP32Servo.h>

#define SDA_ENC 19  
#define SCL_ENC 18
#define AS5600_ADDR 0x36 

#define SDA_NANO 21 
#define SCL_NANO 22

#define NANO_HOMBRO_ADDR 0x10 
#define NANO_CODO_ADDR   0x11 
#define NANO_MUNECA_ADDR 0x13 

TwoWire WireNano = TwoWire(1); 
Adafruit_INA219 ina219; 
Servo gripperServo;

#define VELOCIDAD_SERVO_AUTO   25    
#define VELOCIDAD_SERVO_MANUAL 20    
#define TIEMPO_ESPERA_PUNTOS   1500  


//PINES BASE
#define DIR0         12    
#define STEP0        14    
#define ENA0         27    
#define FIN_CARRERA  17    
#define PIN_PARO     26

//PINES LEDS
#define LED_ROJO     15   
#define LED_VERDE    2    

//PIN SERVO
#define SERVO_PIN    32

#define REDUCCION 19.21
#define ANGULO_HOME 0.0    

// Memoria 
float puntosGuardados[20];
int puntosServoGuardados[20];
int totalPuntos = 0;
bool reproduciendo = false;
int indicePunto = 0;
unsigned long tiempoEsperaPunto = 0;
bool periodoDeGracia = false;
unsigned long inicioGracia = 0;

volatile bool emergenciaActiva = false; 

float degAngle = 0, lastAngle = 0;
long vueltas = 0; 
float anguloMotor = 0, anguloSalida = 0, anguloFinal = 0, offset = 0, objetivo = 0;
bool homingHecho = false, iniciarHoming = false, enMovimientoAngulo = false;
float tolerancia = 0.3;
int velMax = 500, velMin = 1200;

String comando = "STOP";
String ultimoCmd = "";
unsigned long lastI2CSend = 0;
const int intervaloI2C = 100; 
long pasosM0 = 0; 

bool hombroEnMovimiento = false;
bool codoEnMovimiento = false;
bool munecaEnMovimiento = false;
unsigned long lastNanoCheck = 0;

// VARIABLES SERVO
int anguloServo = 0;         
int objetivoServo = 0;       
bool garraEnMovimiento = false;
float umbralCorrienteMA = 2000.0;
unsigned long lastServoTime = 0;

typedef struct { char msg[24]; } Packet;
Packet packet;

void actualizarLeds() {
  bool paroFisicoActivo = (digitalRead(PIN_PARO) == HIGH);
  if (paroFisicoActivo || emergenciaActiva) {
    digitalWrite(LED_ROJO, HIGH); digitalWrite(LED_VERDE, LOW);
  } 
  else if (!homingHecho) {
    static unsigned long lastBlink = 0;
    static bool estadoRojo = LOW;
    digitalWrite(LED_VERDE, LOW);
    if (millis() - lastBlink > 300) {
      estadoRojo = !estadoRojo; digitalWrite(LED_ROJO, estadoRojo); lastBlink = millis();
    }
  } 
  else {
    digitalWrite(LED_ROJO, LOW);
    if (!reproduciendo) { digitalWrite(LED_VERDE, HIGH); }
  }
}

void enviarI2C(uint8_t addr, String msg) {
  msg.toUpperCase();
  WireNano.beginTransmission(addr); WireNano.write((const uint8_t*)msg.c_str(), msg.length()); WireNano.endTransmission();
}

void gestionarEnviosI2C() {
  if (comando.startsWith("M2") || comando.startsWith("GOTO_M2")) { enviarI2C(NANO_HOMBRO_ADDR, comando); } 
  else if (comando.startsWith("M3") || comando.startsWith("GOTO_M3")) { enviarI2C(NANO_CODO_ADDR, comando); } 
  else if (comando.startsWith("M4") || comando.startsWith("GOTO_M4")) { enviarI2C(NANO_MUNECA_ADDR, comando); }
  else if (comando == "SAVE" || comando == "DELETE") {
    enviarI2C(NANO_HOMBRO_ADDR, comando); enviarI2C(NANO_CODO_ADDR, comando); enviarI2C(NANO_MUNECA_ADDR, comando);
  } 
  else if (comando == "STOP") {
    enviarI2C(NANO_HOMBRO_ADDR, "M2_STOP"); enviarI2C(NANO_CODO_ADDR, "M3_STOP"); enviarI2C(NANO_MUNECA_ADDR, "M4_STOP");
  }
}

void controlMovimientoPorAngulo() {
  if (objetivo > 360.0) objetivo = 360.0;
  if (objetivo < -15.0) objetivo = -15.0;
  static int estable = 0;
  float error = objetivo - anguloFinal;
  if (abs(error) > tolerancia) {
    estable = 0; digitalWrite(DIR0, (error > 0) ? HIGH : LOW); 
    int velocidad = constrain(map(abs(error), 0, 30, velMin, velMax), velMax, velMin);
    int pasos = constrain(map(abs(error), 0, 50, 2, 50), 1, 20);
    for (int i = 0; i < pasos; i++) moverUnPaso(velocidad);
  } else {
    estable++; if (estable > 10) { enMovimientoAngulo = false; estable = 0; }
  }
}

void hacerHoming() {
  digitalWrite(ENA0, LOW); 
  delay(1000);
  if (digitalRead(FIN_CARRERA) == LOW) {
 
    Serial.println("HOMING BASE zona de 60°");
    digitalWrite(DIR0, LOW); 
    while (digitalRead(FIN_CARRERA) == LOW && digitalRead(PIN_PARO) == LOW && !emergenciaActiva) { 
      moverUnPaso(800); 
    }
    if (digitalRead(PIN_PARO) == HIGH || emergenciaActiva) { abortarTodoHoming(); return; }
    delay(300);
    
    Serial.println("BASE Zona libre");
    digitalWrite(DIR0, HIGH); 
    while (digitalRead(FIN_CARRERA) == HIGH && digitalRead(PIN_PARO) == LOW && !emergenciaActiva) { 
      moverUnPaso(1600);
    }
  } 
  else {
    Serial.println("BASE zona libre de 300°");
    digitalWrite(DIR0, HIGH); 
    while (digitalRead(FIN_CARRERA) == HIGH && digitalRead(PIN_PARO) == LOW && !emergenciaActiva) { 
      moverUnPaso(800); 
    }
    if (digitalRead(PIN_PARO) == HIGH || emergenciaActiva) { abortarTodoHoming(); return; }
    delay(200);

    digitalWrite(DIR0, LOW); 
    for (int i = 0; i < 350; i++) {
      if (digitalRead(PIN_PARO) == HIGH || emergenciaActiva) { abortarTodoHoming(); return; }
      moverUnPaso(800);
    }
    delay(200);
    
    digitalWrite(DIR0, HIGH); 
    while (digitalRead(FIN_CARRERA) == HIGH && digitalRead(PIN_PARO) == LOW && !emergenciaActiva) { 
      moverUnPaso(1600); 
    }
  }
  
  if (digitalRead(PIN_PARO) == HIGH || emergenciaActiva) { abortarTodoHoming(); return; }
  
  delay(5); actualizarPosicion(); offset = anguloSalida - ANGULO_HOME; 
  homingHecho = true; pasosM0 = 0; objetivo = 0; comando = "STOP"; delay(500); 

  enviarI2C(NANO_HOMBRO_ADDR, "M2_HOME"); delay(100); 
  enviarI2C(NANO_CODO_ADDR, "M3_HOME"); delay(100);
  enviarI2C(NANO_MUNECA_ADDR, "M4_HOME"); delay(100);
  
  Serial.println("test mecánico Gripper");
  for (int ang = 0; ang <= 170; ang += 2) {
    gripperServo.write(ang);
    delay(15); 
  }
  delay(300);
  for (int ang = 170; ang >= 0; ang -= 2) {
    gripperServo.write(ang);
    delay(15);
  }
  
  anguloServo = 0;
  gripperServo.write(anguloServo);
  
  Serial.println("SISTEMA EN HOME"); comando = "STOP"; 
}

void abortarTodoHoming() {
  homingHecho = false;
  enviarI2C(NANO_HOMBRO_ADDR, "STOP"); enviarI2C(NANO_CODO_ADDR, "STOP"); enviarI2C(NANO_MUNECA_ADDR, "STOP");
  comando = "STOP"; Serial.println("⚠️ HOMING ABORTADO");
}

void dispararPunto() {
  objetivo = puntosGuardados[indicePunto]; enMovimientoAngulo = true;
  
  objetivoServo = puntosServoGuardados[indicePunto]; 
  garraEnMovimiento = true; 

  hombroEnMovimiento = true; codoEnMovimiento = true; munecaEnMovimiento = true;
  tiempoEsperaPunto = 0; comando = "ANGULO_AUTO";
  
  enviarI2C(NANO_HOMBRO_ADDR, "SYNC_" + String(indicePunto)); 
  enviarI2C(NANO_CODO_ADDR, "SYNC_" + String(indicePunto)); 
  enviarI2C(NANO_MUNECA_ADDR, "SYNC_" + String(indicePunto)); 
  periodoDeGracia = true; inicioGracia = millis();
}
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
